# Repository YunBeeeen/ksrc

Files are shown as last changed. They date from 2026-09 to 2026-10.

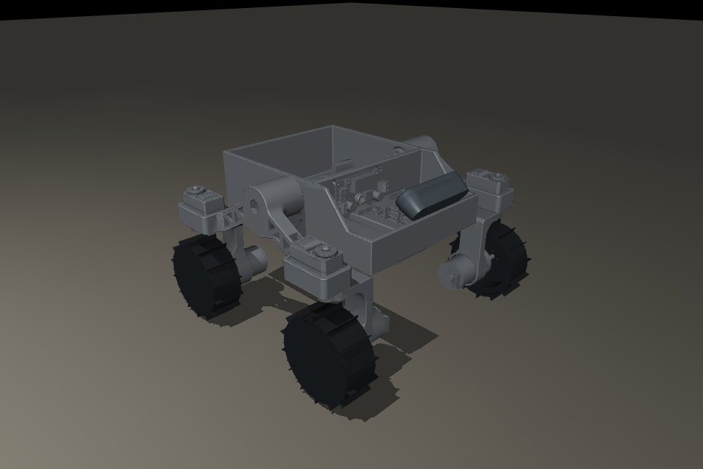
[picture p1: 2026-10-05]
ros/rover_description/docs/assembly_preview.png

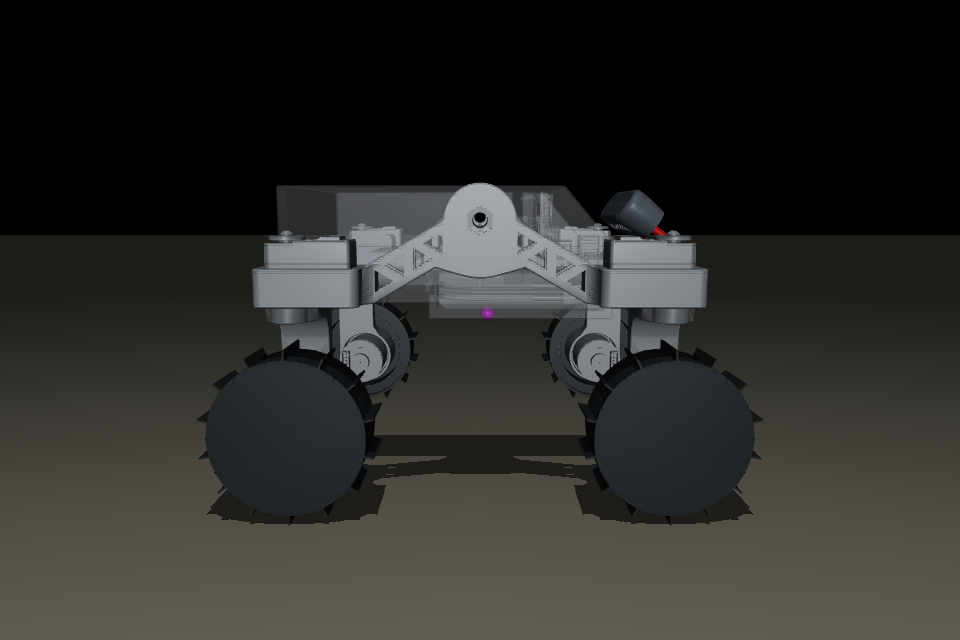
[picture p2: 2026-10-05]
ros/rover_description/docs/camera_35deg_com.png

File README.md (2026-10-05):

# KSRC 2026 — 4륜 독립조향 우주로버

2026 대한민국 우주로버 챌린지(우주항공청) 출전 로버의 **저수준 제어기 · 시뮬레이터 ·
강화학습** 코드베이스임.

바퀴 4개를 각각 독립 **조향** + **구동** 하는 스워브 방식임. 중앙 베벨 디퍼렌셜이
좌우 로커를 1:1 역방향으로 묶어 울퉁불퉁한 지형에서 네 바퀴 접지를 유지함.

| 항목 | 값 |
|---|---|
| 총질량 | 2.26 kg (규정 3 kg 이하) |
| 크기 | 284 × 263 × 173 mm (규정 300×300×200 이하) |
| 휠베이스 / 트랙 | 210 / 265 mm (조향축 = 바퀴 중심, 2026-10-03 실측. 이전 STL 183.6 / 236.7) |
| 바퀴 | 지름 79.9 mm, 폭 35 mm, 그라우저 약 28개 |
| 지상고 | 9.6 mm (다리 하우징 최저점 기준) |
| 구동 | SPG30E-GR131 ×4 (12V, 131:1, 76 rpm 무부하, 20 kg·cm 정지토크) |
| 조향 | FEETECH STS3215 ×4 (반이중 UART 버스, 1 Mbaud). 가동범위: 바퀴별 ±100° (펌웨어 `joint.c` = 시뮬 `config.steer_*_deg`, 조립 후 실측으로 확정) |
| 최고 속도 | 0.318 m/s |
| 배터리 | 3S 650mAh 120C 리포 |
| MCU / SBC | STM32 Nucleo-F446RE / Raspberry Pi 5 + AI HAT |

---

## 시스템 구조

```
        조작자 / 자율
             │
    ┌────────┴────────┐
    │  Raspberry Pi 5 │   pi/teleop        조이스틱 → cmd_vel
    │                 │   Nav2 (MPPI/Omni) 경로 → cmd_vel   ← 시뮬 검증 완료
    │                 │   (계획) D435 ICP  대회장 맵 정합 → 절대 위치
    │                 │   RL 정책          cmd_vel 위의 잔차 보정
    └────────┬────────┘
             │  아스키/바이너리 시리얼 (115200)
    ┌────────┴────────┐
    │ Nucleo-F446RE   │   swerve_kinematics.c   cmd_vel → 바퀴 4개 각·속도
    │                 │   swerve_fold_to_range  바퀴별 가동범위 안 등가해 선택
    │                 │   drive_align_gate.c    큰 조향 전환 중 구동 보류
    │                 │   spi_link.c            Pi SPI2 명령/텔레메트리 프레임
    │                 │   mdd3a_driver.c        PWM
    │                 │   encoder.c             엔코더 4채널
    └────────┬────────┘
             │
      구동모터 ×4      조향서보 ×4
```

명령 인터페이스는 `cmd_vel = (vx, vy, ω)` 한 지점으로 모임. 조이스틱 · Nav2 ·
RL 잔차가 모두 같은 지점에 붙으므로 서로 교체 가능함.

**시뮬레이터가 펌웨어 C 코드를 그대로 호출함.** `sim/build.sh` 가
`firmware/common/*.c` 를 `libksrc_common.so` 로 빌드하고 파이썬이 ctypes 로 부름.
기구학을 파이썬으로 재구현하면 언젠가 반드시 어긋나는데, 정책이 기구학 위의
**잔차**를 학습하는 구조라 어긋나는 순간 정책이 통째로 무의미해짐.

---

## 저장소 구조

```
firmware/
  common/                   MCU 비의존 순수 C + 호스트 유닛테스트
  src2026-rover-firmware/   보드에 올라가는 CubeIDE 프로젝트 (별도 git 저장소)
pi/teleop/                  조이스틱 텔레옵 (Python)
ros/                        ROS2 / Nav2 통합
  make_maps.py              주행가능 마스크 -> Nav2 정적 맵
  maps/                     arena_{sand,rock}.{pgm,yaml}
  mujoco_bridge.py          MuJoCo <-> ROS2 (/odom /tf 발행, /cmd_vel 구독)
  nav2_params.yaml          Nav2 파라미터 (MPPI motion_model=Omni)
  nav2_ksrc.launch.py       최소 구성 런치
  rviz/ksrc.rviz            RViz 설정
sim/
  ksrc_common.py            펌웨어 C 를 ctypes 로 호출
  rl/                       MuJoCo 물리 + 강화학습
CLI.md                      전체 실행 명령 모음
```

### 폴더별 문서

| 폴더 | 문서 | 내용 |
|---|---|---|
| `firmware/` | [README](firmware/README.md) · [CLI](firmware/CLI.md) | STM32 저수준 제어기: 핀, 50Hz 제어주기, 설정값, 조향 영점·구동 세팅, 터미널 명령 |
| `sim/` | [README](sim/README.md) · [CLI](sim/CLI.md) | MuJoCo 물리, 강화학습 환경·보상, 학습·평가·재생, 설계상 선택, 학습 결과 |
| `ros/` | 이 문서 아래 "ROS2 / Nav2" | Nav2·RViz 클릭 주행, 대회맵 텔레옵 |
| `pi/` | [firmware/CLI.md §5·6](firmware/CLI.md) | 조이스틱 텔레옵, Pi ↔ Nucleo SPI 링크 |

---

## ROS2 / Nav2 실행

전체 인자는 **[CLI.md](CLI.md)** 에 있다. 학습·평가 명령은 [sim/CLI.md](sim/CLI.md).

### Nav2 + RViz 로 클릭 주행

```bash
# 브리지 + Nav2 + RViz 를 한 번에 실행한다 (기존 별도 브리지는 먼저 종료).
cd /home/eomyunbeen/ksrc/ros && source /opt/ros/humble/setup.bash
python3 make_maps.py                      # 맵이 없으면 한 번
# 아래 둘 중 하나만 실행
ros2 launch nav2_ksrc.launch.py terrain:=sand           # 순수 IK
ros2 launch nav2_ksrc.launch.py terrain:=sand rl:=true  # 구형 s2 정책 적용 확인용
```

브리지는 `/cmd_vel`을 0.10초 시정수로 필터링해 `/cmd_vel_filtered`로 내고,
`/rl_action`(정규화 행동), `/rl_delta`(요청 보정), `/cmd_vel_applied`(포화 후 IK 입력)를
발행한다. 보정 적용은 `/cmd_vel_filtered`와 `/cmd_vel_applied`를 비교하면 된다.
`ros2 service call /set_rl std_srvs/srv/SetBool '{data: false}'`로 주행 중 끄고
`'{data: true}'`로 다시 켤 수 있다. 정책 모델은 `rl_model`, `rl_vecnorm` 런치
인자로 바꿀 수 있다. `cmd_filter_tau:=0`은 명령 필터 비교용이다.
기본 `rl:=true`가 불러오는 `runs/s2`는 이번 경로·관측 수정 이전 모델이므로
성능 개선 판정에는 쓰지 않는다. 새 모델은 재학습 후 `rl_model`과 `rl_vecnorm`을
명시한다.

RViz 상단 **"2D Goal Pose"** 로 지도를 클릭하면 로버가 그쪽으로 감.
회색이 주행가능, 검정이 통과 불가(경사 21° 초과)임.
목표 허용오차가 0.15m 이므로 로버 바로 옆을 찍으면 이미 도착한 것으로 판정될 수 있다.
이 런치는 시뮬 전용 ROS 도메인 77과 localhost 통신을 사용해 다른 ROS 노드의
`/odom`·`/map_server`와 섞이지 않게 한다. 진단 명령도 같은 도메인에서 실행한다:

```bash
source /opt/ros/humble/setup.bash
export ROS_DOMAIN_ID=77 ROS_LOCALHOST_ONLY=1
ros2 lifecycle get /bt_navigator         # active 여야 목표를 받는다
ros2 topic hz /odom                       # 브리지 위치가 계속 발행되는지 확인
```

전복 시 브리지는 구동을 멈추되 물리는 계속 진행하며, 자동으로 스폰으로 순간이동하지 않는다. 다시 시작하려면 별도 터미널에서
위 두 환경변수를 설정하고 `ros2 service call /reset_sim std_srvs/srv/Trigger '{}'` 를 실행한다. 같은 초기 스폰으로 돌아간다.
RViz 의 "2D Pose Estimate" 는 시뮬 스폰을 바꾸지 않는다. RViz 주행에서 RL 잔차는
런치 인자 `rl:=true`를 준 경우에만 적용된다.

컨트롤러는 **MPPI (`motion_model: Omni`)** 를 씀. `nav2_regulated_pure_pursuit_controller`
는 differential/ackermann 용이라 `(v, ω)` 만 내고 스워브의 게걸음(`vy`)을 버림.
실측으로 MPPI 가 `vy = 0.057` 을 명령하는 것을 확인함.

측위는 브리지가 `map→odom` 을 **항등으로** 발행함 (참값). 그래서 "Nav2 가 우리 로버에
맞게 도는가" 만 남고 측위 문제가 섞이지 않음. 실제 측위(D435 지형 ICP)가 되면 그
항등 변환만 갈아끼우면 됨.

Nav2 정적 맵은 경사·단차의 통행 가능성만 표시한다. `drivable_mask`의 0.16m 창은
지형 기울기를 측정하는 규모이며 차체 충돌 반경이 아니다. Nav2에는 바퀴 위치와
반경에서 계산한 약 0.21m 풋프린트와 0.24m inflation을 적용한다 (2026-10-03 실측 치수, 이전 0.19/0.22). 목표점이
턱에 너무 가까우면 반경 밖의 도달 가능한 지점으로 경로가 끝날 수 있다
(플래너 허용오차 0.15m). 순수 IK 경로도 같은 중심 이격 기준으로 만든다.

격리된 Nav2 검증에서 턱을 사이에 둔 `(-1.1, 0.2) → (0.4, 0.2)` 경로의
통행 불가 영역 최소 이격은 기존 약 3cm에서 수정 후 22.1cm로 늘었다 (이전 치수 기준 기록).
기본 스폰 `(0.121, 0.661)`에서 `(-1.1, 0.2)`로 실제 MuJoCo 주행도 성공했고,
로버 중심 최소 이격은 23.5cm였다. 이 검증은 순수 IK, 참값 측위 조건이다.

### 대회맵 + 기존 조이스틱 텔레옵

첫 터미널에서 대회맵, MuJoCo 로버, RViz를 띄운다. 텔레옵 모드에는 Nav2
컨트롤러를 띄우지 않아 `/cmd_vel` 명령이 충돌하지 않는다.

```bash
cd ~/ksrc/ros
source /opt/ros/humble/setup.bash
ros2 launch nav2_ksrc.launch.py terrain:=sand mode:=teleop
```

두 번째 터미널에서 **기존** 마우스 조이스틱을 ROS 모드로 실행한다. 왼쪽 패드로
전후·게걸음, 오른쪽 패드 또는 Q/E로 회전하고 스페이스바로 멈춘다.
급격히 주행 방향을 바꾸면 텔레옵 브리지가 먼저 감속한다. 네 바퀴가 새 방향으로
조향된 뒤 구동하는 규칙은 학습·평가·RViz 주행에도 공통 적용된다.
`teleop_guard:=false`는 사전 감속만 끄고,
`drive_align_gate_deg:=0`은 공통 조향각 구동 게이트를 끈다.

```bash
cd ~/ksrc
source /opt/ros/humble/setup.bash
export ROS_DOMAIN_ID=77 ROS_LOCALHOST_ONLY=1
python3 pi/teleop/teleop_joystick.py --ros --max-lin 0.25 --max-ang 0.8
```

`terrain:=rock`은 암석 대회맵으로 바꾼다. 이 모드의 RViz는 맵과 위치를 보여주는
화면이고 목표 주행 명령은 받지 않는다. 기존 `--port /dev/ttyACM0` 방식은 실기
Nucleo용 직렬 경로로 그대로 유지된다. 규사맵에서는 최초 스폰과 `/reset_sim`
위치를 3° 이하 평탄 구역으로 제한한다. [세 모드의 전체 CLI](CLI.md#6-대회맵-주행-rviz-목표-또는-텔레옵).

### 펌웨어 · 실기 텔레옵

빌드·플래시·터미널 명령·조향 영점·구동모터 확인·조이스틱 주행은
**[firmware/CLI.md](firmware/CLI.md)**, 설정값은 [firmware/README.md](firmware/README.md).

```bash
cd firmware/src2026-rover-firmware && ./build.sh --flash
python3 pi/teleop/teleop_joystick.py --port /dev/ttyACM0 --max-lin 0.15 --max-ang 0.8   # 저장소 루트에서
```

---

## 설계상 중요한 선택

시뮬·학습 쪽 설계 결정(잔차 정책 구조, 흙 모델, 보상, 랜덤화 등)은
[sim/README.md](sim/README.md#설계상-중요한-선택)로 옮겼다.

---

## 현재 상태

| 항목 | 상태 |
|---|---|
| 펌웨어 | 플래시·터미널·기구학 주행·워치독은 **이전 구조**에서 실기 검증. 2026-09-29 이후 50Hz 제어주기·정렬 게이트·SPI2 링크·IMU·서보 피드백으로 재구성 — **미플래시, 실기 미검증**. 조향 영점·바퀴별 범위·구동모터 부호는 조립 후 확인 |
| 시뮬 물리 | 검증 13종 통과. 슬립모델이 고착 재현 확인 |
| 지형 | 실측 규사 경사지형(기복 450 mm, 최대 30°) 통계에 맞춘 절차 생성 확인 |
| 경로추종 | `s4_route_fix` 400만 스텝 모델은 미학습 규사 경로에서 순수 IK보다 횡오차·슬립·잔차 포화가 커졌다. 현재 보상 `balanced`는 수정 후 **아직 재학습·성능 검증 전** |
| 측위 | **미해결.** 엔코더+IMU 데드레커닝은 1.7 m 주행에 845 mm 오차(슬립 때문). D435 + 대회장 맵 ICP 가 기하적으로 가능함을 확인, 미구현 |
| Nav2 | **시뮬에서 동작 확인.** MPPI(Omni) 주행과 선택적 `rl:=true` 잔차 적용을 `/goal_pose` 종단 시험으로 확인. 정책 적용은 성능 개선 검증과 별개이며 실기는 측위 선행 |
| 텔레옵 + 대회맵 | 기존 pygame 조이스틱의 ROS 모드에서 `/cmd_vel`→MuJoCo 이동·패드 해제 후 정지, `/map` 발행 종단 시험 통과 |
| teacher-student | teacher 가 특권 잠재변수를 거의 안 씀(ablation 노이즈 수준) → 증류 보류 |

학습 결과 상세(`s3_path_reward` 검증 등)와 알려진 제약은 [sim/README.md](sim/README.md#학습-현황).

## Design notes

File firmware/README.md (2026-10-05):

# KSRC 로버 펌웨어 (STM32 Nucleo-F446RE)

4륜 독립조향 스워브 로버의 저수준 제어기. 차체 속도 명령 `(vx, vy, ω)` 를 받아
바퀴 4개의 조향각(STS3215 서보)과 구동(MDD3A + 기어드 DC 모터)으로 바꾸고,
엔코더·서보·IMU 값을 Raspberry Pi 로 올려 보낸다.

> 실행 명령만 필요하면 **[CLI.md](CLI.md)**. 이 문서는 설정값과 구조의 정본이다.
> 상태 기준일: 2026-10-03. 2026-09-29 이후 변경(50Hz 제어주기, 정렬 게이트, SPI2 링크,
> IMU, 서보 피드백)은 **빌드는 되지만 실기 검증 전**이다.

---

## 1. 폴더 구조

```
firmware/
├─ README.md                  이 문서 (설정값 정본)
├─ CLI.md                     실행 명령 모음
├─ common/                    MCU 비의존 순수 C. 호스트 gcc 테스트 + 시뮬이 ctypes 로 같은 코드 호출
│   swerve_kinematics.c         역기구학 + 가동범위 안 등가해 선택 (swerve_fold_to_range)
│   drive_align_gate.c          큰 조향 전환 중 구동 보류
│   spi_link.c                  Pi <-> Nucleo SPI 144바이트 프레임 (CRC16)
│   mdd3a_driver.c              m/s -> 정규화 duty
│   sts3215_protocol.c          (시뮬 전용) 서보 패킷
│   teleop_protocol.c           (시뮬 전용) UART 바이너리 프레임
│   tests/                      호스트 유닛테스트
└─ src2026-rover-firmware/    보드에 올라가는 프로젝트 (Makefile + build.sh)
    Core/Src/main.c             50Hz 제어주기, 터미널 명령, 텔레메트리 조립
    Core/Src/joint.c            서보 각도 <-> 위치값, 바퀴별 가동범위, 피드백 읽기
    Core/Src/sts3215.c          STS3215 버스 (USART3 반이중)
    Core/Src/motor.c/encoder.c  MDD3A PWM 8채널, 엔코더 타이머 4개
    Core/Src/pi_spi.c           SPI2 슬레이브 (Pi 링크, DMA)
    Core/Src/imu_ism330.c       ISM330DHCX (SPI3 마스터)
    Core/Src/{swerve_kinematics,drive_align_gate,spi_link,mdd3a_driver}.c
                                -> ../../../common/ 심볼릭 링크
```

`common/` 의 C 를 고치면 시뮬도 같이 바뀐다 (`sim/build.sh` 로 `.so` 재빌드).

---

## 2. 하드웨어와 핀

MCU 클럭: **HSI 16 MHz, PLL 없음** (APB1 = APB2 = 16 MHz).
USART2/USART3/SPI2/SPI3 는 CubeMX 가 아니라 **레지스터로 직접** 설정한다.
`.ioc` 로 Generate Code 를 하면 `MX_SPI2_Init()`/`MX_SPI3_Init()` 이 생기는데 호출하지
않는다 (HAL SPI 가 Makefile 에 없어 링크도 깨진다).

| 기능 | 주변장치 | 핀 | 설정 |
|---|---|---|---|
| 터미널 / 조이스틱 | USART2 (ST-Link VCP) | PA2 TX, PA3 RX | 115200 8N1, RX 인터럽트 |
| 조향 서보 버스 | USART3 반이중 | PB10 (오픈드레인+풀업) | 1 Mbps |
| Pi 링크 | SPI2 슬레이브 + DMA1 S3/S4 | PB12 CS (GPIO+EXTI, 소프트웨어 NSS), PB13 SCK, PC2 MISO, PC3 MOSI | 모드 0, 8비트, Pi 쪽 1 MHz 권장 (상한 8 MHz) |
| IMU | SPI3 마스터 | PC10 SCK, PC11 MISO, PC12 MOSI, PC9 CS | 모드 0, 1 MHz |
| 구동 MOTOR1 (LF) | TIM2 CH1/CH2 | PA5 / PB3 | MDD3A #1 M1 (A/B) |
| 구동 MOTOR2 (LB) | TIM12 CH1/CH2 | PB14 / PB15 | MDD3A #1 M2 |
| 구동 MOTOR3 (RF) | TIM3 CH1/CH2 | PA6 / PA7 | MDD3A #2 M1 |
| 구동 MOTOR4 (RB) | TIM3 CH3/CH4 | PB0 / PB1 | MDD3A #2 M2 |
| 엔코더 1~4 (LF, LB, RF, RB) | TIM1 / TIM4 / TIM5 / TIM8 | PA8·PA9 / PB6·PB7 / PA0·PA1 / PC6·PC7 | x4 쿼드러처 (TIM5 만 32비트) |

PWM: ARR 799 → 약 20 kHz, duty -799 ~ +799. MDD3A 는 PWM+PWM 방식 (정방향 A, 역방향 B).
서보 VCC 는 STM32 에 연결하지 않는다 (12V 외부 전원, GND 만 공통).

---

## 3. 제어 흐름 (50 Hz)

```
UART "V vx vy ω"  ─┐
SPI2 명령 프레임   ─┴─> 목표 (vx, vy, ω) 만 갱신
                          │
20 ms 마다 (main.c while 루프)
  1. 엔코더 속도 추정 (dt 는 DWT 사이클 카운터)
  2. 센서: 서보 4개 피드백 (위치·속도·부하·전압·온도·상태), IMU 1샘플
  3. 워치독: 500 ms 무명령 -> 목표 0 (조향각은 유지)
  4. swerve_ik_compute         -> 모듈별 (각, 속도), 바퀴 속도 상한 초과 시 전체 비율 축소
  5. swerve_fold_to_range      -> 바퀴별 가동범위 안의 등가각 (θ 또는 θ±180° + 역회전)
  6. 조향 SYNC_WRITE           -> 모듈 순서를 서보 순서로 재배열
  7. drive_align_gate          -> 큰 조향 전환 중이면 구동 0
  8. 구동 PWM                  -> MOTOR_DRIVE_SIGN 적용
  9. 텔레메트리 프레임          -> 다음 SPI 전송에 실림
```

3~9 는 텔레옵(첫 구동 명령)이 시작된 뒤에만 돈다. 그 전에는 `T`, `MOT`, `MTEST` 같은
수동 명령이 액추에이터를 쓴다.

---

## 4. 설정값

**확정** = 실측·결정됨, **임시** = 조립 후 확인 필요, **가정** = 데이터시트/추정.

### 4.1 서보 배치와 조향

| 설정 | 위치 | 현재 값 | 상태 |
|---|---|---|---|
| 서보 ID ↔ 바퀴 | `joint.c` `joint_config[]` | 서보1 LF, 서보2 LB, 서보3 RF, 서보4 RB | 확정 |
| 모듈 → 서보 | `main.c` `SWERVE_MODULE_SERVO` | `{0, 2, 1, 3}` (FL→서보1, FR→서보3, RL→서보2, RR→서보4) | 확정 |
| 조향 영점 | 서보 EEPROM (`ZERO`) | 미기록 | **임시** — 조립 후 |
| 영점 위치값 | `joint.c` `.offset` | 2048 (`ZERO` 가 현재 자세를 2048 로 기록) | 확정 |
| 조향 방향 | `joint.c` `.dir` | 전부 +1 | **임시** — `T 30` 이 위에서 반시계면 +1. 뒤쪽 서보(LB, RB)는 앞쪽과 **월드 z축 기준 180°** 돌려 장착(둘 다 아래를 봄) → 회전 방향은 같으므로 네 서보 `dir` 부호는 같아야 함. 영점 차이는 `ZERO ALL` 이 흡수 |
| 가동범위 | `joint.c` `.min_deg/.max_deg` | 전부 -100° ~ +100° | **임시** — 조립 후 실측. 폭 ≥ 180° 유지 |
| 시뮬 가동범위 | `sim/rl/config.py` `steer_lo_deg/steer_hi_deg` | 전부 ±100° (순서 FL, FR, RL, RR) | 펌웨어와 **같이** 고칠 것 |
| 조향 0° 의 뜻 | — | 바퀴 정면, 구동모터 몸체 안쪽, + 는 위에서 반시계 | 확정 (시뮬과 동일) |
| 서보 최고속 | `joint.c` `joint_goal_speed` | 0 = 서보 최대 (제한 없음). 터미널 `S` 로 변경 | 단위 step/s, 4096 step = 360° |
| 서보 가속도 | `joint.c` `joint_init()` | 50 | 가정 (단위 미실측) |
| 서보 수신 타임아웃 | `sts3215.c` `STS_RX_TIMEOUT_MS` | 3 ms | 확정 |
| 서보 읽기 실패 재시도 | `main.c` `SERVO_RETRY_TICKS` | 25 주기 (0.5 s), 한 주기에 1개만 재시도 | 확정 |

±100° 에서 모든 방향이 나온다: 한 방향의 해는 θ(정회전)와 θ±180°(역회전) 두 개이고
가동 폭이 200° 라 항상 하나는 범위 안이다. ±80°~±100° 는 두 해가 겹쳐 경계 근처
흔들림에 반전이 생기지 않는다. 경계를 넘으면 180° 반전이 일어나고 그동안 구동은
정렬 게이트가 멈춘다.

### 4.2 구동과 엔코더

| 설정 | 위치 | 현재 값 | 상태 |
|---|---|---|---|
| 모터 번호 ↔ 바퀴 | — | MOTOR1 LF, MOTOR2 LB, MOTOR3 RF, MOTOR4 RB (조향 서보와 같은 배치) | **확정 2026-10-03** |
| 모듈 → 구동모터 | `main.c` `SWERVE_MODULE_MOTOR` | `{MOTOR1, MOTOR3, MOTOR2, MOTOR4}` (FL, FR, RL, RR) | 확정 |
| 구동 부호 | `main.c` `MOTOR_DRIVE_SIGN[MOTOR1..4]` | −1, −1, +1, +1 (LF, LB, RF, RB) | 2026-10-03. 모터를 넷 다 같은 방식으로 달아 **좌우 대칭** (L −1, R +1). RF 는 −1 로 관찰돼 확인 필요 |
| 엔코더 부호 | `main.c` `ENCODER_SIGN[MOTOR1..4]` | −1, −1, +1, +1 | MOTOR1 이 duty + 에서 tick + (실측) → 구동 부호와 같음. `V 0.05 0 0` 에서 m/s 가 넷 다 + 인지 확인 |
| 기어비 | `main.c` `GEAR_RATIO` | 131 (SPG30E-GR131) | 확정 |
| 엔코더 PPR | `main.c` `ENCODER_PPR` | 16 (x4 → 64, 바퀴 1회전 8384 틱) | **확정 2026-10-03** (무부하 77.8 rpm) |
| 바퀴 반경 | `main.c` `WHEEL_RADIUS_M` | 0.03995 m (지름 79.9 mm, STL) | 가정 (캘리퍼 미실측) |
| 바퀴 최고속 | `main.c` `SWERVE_MAX_WHEEL_MPS` | 0.318 m/s (= duty 100%) | 가정. 실측 무부하 0.325 m/s (+2%) |
| 모듈 위치 | `main.c` `SWERVE_MODULES` | (±0.105, ±0.1325) m (조향축 = 바퀴 중심) | **실측 2026-10-03**. 시뮬 `axle_x=0.105`, `track=0.265` 와 동일 |

조립 전 날것 방향 기록 (`MOT`, 부호 보정 없음, 샤프트 끝에서 볼 때):

| 모터 | duty + | 엔코더 | 날짜 |
|---|---|---|---|
| MOTOR1 | 반시계 | + | 2026-10-03 |
| MOTOR2~4 | | | |

### 4.3 제어주기와 안전

| 설정 | 위치 | 현재 값 |
|---|---|---|
| 제어주기 | `main.c` `CTRL_PERIOD_MS` | 20 ms (50 Hz, 시뮬 `CTRL_HZ` 와 동일) |
| 명령 워치독 | `main.c` `TELEOP_TIMEOUT_MS` | 500 ms → 목표 0 |
| 정렬 게이트 트리거 | `main.c` `DRIVE_GATE_TRIGGER_DEG` | 60° (목표 급변, 또는 목표-실측 차이) |
| 정렬 게이트 해제 | `main.c` `DRIVE_GATE_RELEASE_DEG` | 10° (네 바퀴 실측각 기준) |
| 정렬 게이트 타임아웃 | `main.c` `DRIVE_GATE_MAX_HOLD_MS` | 1500 ms → 강제 해제 + `GATE_TIMEOUT` 플래그 |
| 모터 자가시험 | `main.c` `s_mtest_enabled` | 기본 OFF (`MTEST` 로만) |
| 로그 | `main.c` `s_log_enabled` | 부팅 시 ON, 텔레옵 시작 시 자동 OFF |

안전장치 요약:
- 손 떼면(속도 0) 조향각을 유지한다. 0° 로 튀지 않는다.
- 조향 해는 항상 가동범위 안. `joint.c` 가 한 번 더 클램프한다 (`T` 포함).
- 서보는 위치값 사이를 직선으로 움직여, 범위 안 두 각 사이의 이동 경로도 범위 안이다.
- 큰 조향 전환 중에는 구동 0 (정렬 게이트). 최대 1.5 초.
- 명령이 끊기면 500 ms 뒤 정지. 조이스틱 프로그램은 창 포커스 잃음·스페이스·종료 시 0 전송,
  패드 중심 10% 데드존.

### 4.4 IMU (ISM330DHCX)

| 설정 | 값 |
|---|---|
| 가속도 | 208 Hz, ±4 g (0.122 mg/LSB) |
| 자이로 | 208 Hz, ±500 dps (17.5 mdps/LSB) |
| 기타 | BDU=1, 주소 자동증가. 부팅 시·1초마다 WHO_AM_I(0x6B) 확인, 끊기면 재초기화 |
| 좌표계 | **센서 좌표계 원시값**. 차체 좌표계 회전은 Pi 에서 (장착 방향 확인 필요) |

---

## 5. 통신

### 5.1 USART2 아스키 (터미널 · 조이스틱)
한 줄 명령. 구동은 `V vx vy ω` (m/s, m/s, rad/s, x=전진 y=좌측 ω=반시계 +).
전체 명령은 [CLI.md](CLI.md#3-터미널-명령).

### 5.2 SPI2 프레임 (Pi)
정본: `common/spi_link.h`. Pi 쪽: `pi/common/nucleo_link.py` (`SpiLink`).

- 양방향 **144 바이트 고정**, 동기 `A5 5A`, 버전 2, CRC-16/CCITT-FALSE.
- Pi → Nucleo: 속도 명령 (`0x01`) 또는 폴링 (`0x00`, 워치독 갱신 안 함).
- Nucleo → Pi: 한 제어주기의 값 전부 + Nucleo 시각 `t_ms`.
  구동(적용 명령, 엔코더 틱, 바퀴 속도, duty), 조향(목표각, 실측 각·속도·부하·전압·온도·상태,
  유효 비트), IMU(원시 6축), 상태 플래그(워치독, 게이트 대기, 게이트 타임아웃, 서보 읽기 실패,
  조향 클램프, IMU 유효, 명령 출처). 배열은 모듈 순서 FL, FR, RL, RR.
- 받는 텔레메트리는 **직전 CS 해제까지 만든 것** (0~40 ms 묵음). 같은 `tick` 을 두 번
  받을 수 있다. Nucleo 가 없으면 CRC 실패로 `None`.

---

## 6. 세팅 CLI 요약

자세한 순서와 설명은 [CLI.md](CLI.md).

```bash
# 빌드 + 플래시 (보드 USB 연결)
cd ~/ksrc/firmware/src2026-rover-firmware
./build.sh --flash

# 터미널
python3 -m serial.tools.miniterm /dev/ttyACM0 115200
```

```
LOG                       로그 끄기
SCAN                      서보 ID 1~4 확인
OFF                       토크 해제 -> 네 바퀴 정면 정렬 (모터 안쪽)
ZERO ALL                  영점 기록 (EEPROM)
ON
T 0 0 0 0                 네 바퀴 정면 확인
T 30 / T 0 30 / T 0 0 30 / T 0 0 0 30
                          서보별 방향 확인 (위에서 반시계가 정상, 아니면 joint.c .dir = -1)
S 1500                    (선택) 조향 최고속 제한 ~132°/s
MOT 1 300 1000            구동모터 1 을 duty +300 으로 1초 (바퀴 띄우고)
MOT 1 799 2000            무부하 rpm 확인 (2초 이하로, 16비트 엔코더 한계)
```

```bash
# 조이스틱 (miniterm 닫고, 처음엔 바퀴 띄우고 저속)
cd ~/ksrc
python3 pi/teleop/teleop_joystick.py --port /dev/ttyACM0 --max-lin 0.15 --max-ang 0.8
```

```bash
# 라파에서 (ssh pi@raspberrypi.local, SPI 로 Nucleo 와 통신)
cd ~/ksrc
python3 pi/common/spi_monitor.py         # 텔레메트리 확인 (명령 안 보냄)
python3 pi/common/imu_check.py           # IMU 축·부호 확인 (로버 좌표)
python3 pi/common/udp_spi_bridge.py      # PC 조이스틱 -> SPI 중계 (켜 둔다)
```

```bash
# PC 에서 (조이스틱 창은 PC, 라파가 받아 SPI 로 전달)
python3 pi/teleop/teleop_joystick.py --udp raspberrypi.local --rate 50 --max-lin 0.15 --max-ang 0.8 --monitor
```

---

## 7. 조립 후 반드시 할 것 (주행 전)

| # | 항목 | 고칠 곳 | 방법 |
|---|---|---|---|
| Z1 | 조향 영점 | 서보 EEPROM | `OFF` → 정면 정렬 → `ZERO ALL` → `ON` → `T 0 0 0 0` |
| Z2 | 조향 방향 | `joint.c` `.dir` | `T 30` 을 서보별로, 위에서 반시계면 +1 |
| Z3 | 가동범위 | `joint.c` `.min/.max_deg` **+** `sim/rl/config.py` | `T` 로 천천히 늘려 간섭각 확인 |
| Z4 | 구동모터 ↔ 바퀴 | `main.c` `SWERVE_MODULE_MOTOR` | 바퀴 띄우고 `MOT n 300 1000` |
| Z5 | 구동 방향 | `main.c` `MOTOR_DRIVE_SIGN` | `V 0.05 0 0` 에서 뒤로 도는 바퀴의 모터 → -1 |
| Z6 | 엔코더 방향 | `main.c` `ENCODER_SIGN` | Z5 후 `LOG` m/s 가 음수인 모터 → -1 |

Z1 → Z2 → Z3 순서대로. 같은 목록이 옵시디언 `실기 확인 목록` 0절에 있다.

---

## 8. 테스트

```bash
# 공용 C (호스트)
cd ~/ksrc/firmware/common/tests
for t in swerve_kinematics drive_align_gate spi_link mdd3a_driver; do
  gcc -std=c99 -Wall -Wextra -I.. -o /tmp/t_$t test_$t.c ../$t.c -lm && /tmp/t_$t | tail -1
done

# Python <-> C 프레임 교차검증
cd ~/ksrc && bash sim/build.sh && python3 pi/common/test_spi_link.py
```

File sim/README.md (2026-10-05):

# KSRC 시뮬레이터 · 강화학습 (`sim/`)

MuJoCo 물리 + 슬립-침하 흙 모델 위에서, 펌웨어와 **같은 C 기구학**(`firmware/common/`)을
ctypes 로 호출해 경로추종 잔차 정책을 학습·평가한다. 로버 전체 개요는 [루트 README](../README.md),
펌웨어 설정은 [firmware/README.md](../firmware/README.md), 전체 학습 명령은 **[CLI.md](CLI.md)**.

> 명령은 특별한 말이 없으면 **저장소 루트(`~/ksrc`) 기준**이다.

---

## 구성

### `sim/rl/` — MuJoCo 물리 + 강화학습

| 파일 | 역할 |
|---|---|
| `config.py` | 로버 물리 파라미터 + 센서/구동 노이즈. 출처를 [확정]/[추정]/[미정] 3등급 표기 |
| `mjcf.py` | config → MuJoCo MJCF 모델 생성 |
| `terramech.py` | 슬립-침하 모델. 고착 재현의 핵심 |
| `terrain.py` | 절차 지형 생성 · 대회장 맵 로드 · 주행가능 마스크 · 미세요철 교란 |
| `path.py` | 기준경로 생성 + 홀로노믹 pure pursuit (Nav2 컨트롤러 미러링) |
| `reward.py` | 단일 보상 함수와 가중치 (`RewardCfg`) |
| `env.py` | Gymnasium 환경 |
| `train.py` | PPO 학습 (stable-baselines3) |
| `eval.py` | 대회장 지형 평가. 고전 제어 기준선 4종과 비교 |
| `traction.py` | 고전 제어 기준선 (경사스케줄 듀티 제한 / 엔코더 TCS) |
| `nets.py` | teacher-student 신경망 (특권 인코더 / 적응 모듈) |
| `distill.py` | teacher → student 증류 (DAgger + 잠재변수 회귀) |
| `probe_teacher.py` | teacher 가 특권정보를 실제로 쓰는지 진단 |
| `view.py` | MuJoCo 뷰어 (정책 재생). `--path` 로 지정 경로, `--stage1` 로 학습 조건 재현 |
| `draw_path.py` | 지형 지도에서 마우스로 경로 찍기 |
| `check_model.py` | 모델 물리 검증 13종 |
| `test_terramech.py` | 견인력 곡선·고착 재현 검증 |
| `plotlog.py` | 학습 로그 → 그림 |
| `draw.py` | 모델 2D 단면 렌더 |

---
---

## 실행 명령

전체 인자는 **[CLI.md](CLI.md)** 에 있음. 아래는 자주 쓰는 것만임.

### 빌드 · 검증

```bash
cd sim && bash build.sh          # 기구학 C → libksrc_common.so
cd rl  && python3 check_model.py # 물리 검증 13종
python3 test_terramech.py        # 견인력 곡선 검증
```

### 학습

```bash
cd sim/rl

# Stage 1 — 경로추종 sanity check (경로 세트 고정, 랜덤화·교란·커리큘럼 OFF)
python3 train.py --steps 1000000 --envs 16 --terrain sand --stage1 --out runs/s5_reward

# Stage 2 — 랜덤화·커리큘럼 켜고 특권 관측(teacher) 붙임
python3 train.py --steps 4000000 --envs 16 --teacher --terrain sand --out runs/foo
```

| 옵션 | 뜻 |
|---|---|
| `--stage1` | 경로 세트 고정(10개) + 랜덤화·노이즈·교란·커리큘럼 전부 OFF. **3D 잔차가 경로추종을 배우는지만** 본다 |
| `--terrain sand\|rock\|proc` | `sand`/`rock` 은 대회장 맵 고정, `proc` 은 절차 생성 |
| `--teacher` | 특권 관측을 붙임 (Stage 2) |
| `--path-seed` / `--n-paths` | Stage 1 경로 세트. **학습과 평가는 다른 seed** 를 써야 함 |
| `--gamma` | 기본 0.998 (시상수 10초). 0.99 는 50Hz 에서 2초라 완주 보너스가 안 보임 |
| `--drive-align-gate-deg` | 기본 10°. 60° 초과 큰 방향 전환 후 구동 재개 오차, 0이면 이전 동작과 비교 |
| `--w-energy` | 현재 미지원: 차축 부하 모델 검증 전에는 오류를 내고 학습을 시작하지 않음 |

### 현재 학습 환경 (`sim/rl/env.py`, `train.py`)

| 구성 | 현재 구현 |
|---|---|
| 물리·제어 주기 | MuJoCo 2 ms 물리 스텝 10회당 정책 1회(50 Hz). 에피소드 최대 20초/1000스텝 |
| 기준 제어 | 경로 위 pure pursuit가 `cmd_nom=(vx, vy, ω)` 생성 → 정책의 3차원 행동 `a∈[-1,1]^3`에 `(0.03 m/s, 0.03 m/s, 0.10 rad/s)`를 곱해 가산 → 공유 C 스워브 IK → 바퀴별 개루프 PWM 듀티·조향각 |
| 저수준 보호 | 바퀴 속도 한계를 넘으면 차체 명령을 공통 비율로 축소. 목표 조향각이 한 주기에 60° 넘게 바뀌면 네 바퀴가 목표의 10° 이내로 정렬될 때까지 구동 보류 |
| 경로·시작 | 경사 최대 21°·단차 최대 40 mm 마스크에서 바퀴 외접 반경 약 0.21 m와 여유 0.03 m를 더 확보한 경로를 생성 (2026-10-03 실측 치수, 이전 0.19 m). 고정 경로 세트에서는 경로 길이의 앞 0~60% 위치에서 시작하고 투영기 두 개도 그 위치에서 초기화. 초기 기수는 그 지점 접선의 ±30° |
| 관측 | 프레임당 36개(`cmd_nom`, 직전 바퀴 명령·엔코더 속도·조향각, 자세·IMU, 0.30/0.80 m 경로 샘플 2점, 횡오차, 기수오차의 cos/sin, 제어기 선행 목표점과 선행 거리 `L`, 직전 행동) × 50프레임 = 1800차원(1초 이력). `--teacher`는 흙·슬립·침하 등 특권값 43개를 추가해 1843차원 |
| 종료 | 목표까지 경로 잔여길이와 실제 거리 **모두** 0.25 m 미만이면 성공. 전복(roll/pitch 60° 초과), 최근 2초 이동 0.02 m 미만이면서 슬립 0.5 초과, 경계 이탈은 실패 종료. 20초 도달은 시간 만료 |

위 Stage 1 실행 예시(`--terrain sand --stage1`)는 고정 경로 10개(seed 1234), 원본 대회 높이맵,
고정 규사 파라미터를 쓴다. **센서·구동 노이즈, 물리 파라미터 랜덤화, 높이맵
교란, 커리큘럼은 꺼진다.** 경로 선택·시작 위치·기수·순항속도는 여전히 매
에피소드 달라진다. `train.py`의 `--terrain` 기본값은 `proc`이므로 Stage 1에서는
`--terrain sand`를 명시한다. `--terrain proc --stage1`은 **경로만 sand 맵에서
생성하고 지형은 proc으로 만드는 불일치**가 있어 현재 비교에 쓰지 않는다.
Stage 1 학습 경로 10개를 2 cm 간격으로 표본화하면 7개에 10° 이상 구간이
있고 6개는 시작점보다 끝점이 높다. 최고 경사는 약 15.3°다. 20° 이상과
30° 램프는 이 고정 경로에 포함되지 않으므로, 현재 Stage 1 결과로 급경사
등판 성능을 판단할 수 없다.
평가 경로는 별도 seed(기본 4321)로 생성해 같은 경로 암기를 구분한다.
암석맵(`rock`)은 이 이격(당시 0.22m, 지금 0.239m)을 적용하면 긴 2m 고정 경로가 나오지 않아
`--terrain rock --stage1`이 오류로 중단된다. 암석 구간은 별도의 짧은 임무
길이·목표 판정이 필요하며, 현재 Stage 1 성능 비교는 규사맵 기준이다.

Stage 2(`--stage1` 없음)는 `--terrain sand|rock`이면 해당 대회 높이맵을 쓰고
매 에피소드 미세요철을 교란한다(기본 표준편차 `0.020 m × 난이도`). `proc`이면
8×8 m 절차 지형을 새로 만든다. 흙 다짐·두께와 바퀴별 마찰 패치, 미측정
질량·로커 스토퍼, 배터리 전압, 엔코더·IMU 오차, 서보 응답, 0~2스텝 제어
지연, 저역통과된 측위 오차를 랜덤화한다. 최근 100개 에피소드 성공률이
60% 이상이면 난이도를 0.05씩 올린다. 학습기는 SB3 PPO, 관측·보상
`VecNormalize`, 기본 `γ=0.998`, 512스텝/환경 rollout, batch 4096,
6 epoch, 학습률 `3e-4`다. `--teacher`는 이 Stage 2의 선택 사항이다.

**현재 관측 제약:** 학습용 추종기는 `L=clip(pp_k_v × v_cruise, pp_l_min, pp_l_max)`만큼
경로를 따라 앞선 목표점 하나를 사용한다. 정책 관측에는 이 점의 차체좌표와
`L`을 별도로 넣고, 0.30/0.80 m 경로 샘플 두 점은 경로 모양을 전달한다.
Pure Pursuit의 목표점 하나와 경로 샘플 두 점은 서로 다른 역할이다.
ROS에서 현재 쓰는 Nav2 Omni MPPI에는 단일 Pure Pursuit 목표점이 없으므로
`/plan`에서 같은 선행 거리 규칙으로 정책용 참조점을 만든다. 나중에 제어기를
Pure Pursuit으로 교체하면 실제 선택한 목표점을 이 필드에 전달해야 한다.
관측이 1650→1800차원으로 바뀌어 기존 체크포인트는 새 환경에 로드되지 않으며
새 입력으로 다시 학습해야 한다. pure pursuit 명령·lookahead와 36차원 프레임의
`e_y`·`e_psi`는 같은 잡음 포함 추정 자세로 계산한다. 보상·종료 판정은 참값을
쓴다. 실기 투입에는 Nav2 측위·경로에서 같은 입력을 공급해야 하며,
ROS 브리지의 관측과 Stage 2 관측의 수치적 일치는 아직 별도 검증이 필요하다.

### 현재 보상 함수 (`sim/rl/reward.py`)

정책 행동을 적용해 **물리를 진행한 뒤** 참 위치로 보상을 계산한다. 경로 호길이
진행량을 `p=clip(Δs/(v_cruise·Δt), 0, 1)`, 실제 이동량을
`m=clip(‖Δxy‖/(v_cruise·Δt), 0, 1)`로 정규화한다. `Δs`는 한 주기의 실제
이동거리로 상한을 두어 코너를 잘라도 가짜 진행 보상을 받지 않는다.
`e_y`는 단조 진행 투영기의 경로 횡오차, `d_route`는 전체 경로 선분까지의
최근접 실거리, `e_psi`는 차체 기수와 경로 접선 사이의 각도다.
실제 이동 방향 `e_course`는 진단으로 기록하지만 현재 보상에는 쓰지 않는다.
경로 중앙으로 복귀하는 대각 이동에 방향 게이트를 걸면 교정 행동도 벌주기 때문이다.

```text
G = exp(-(e_y / 0.08 m)^2) · max(0, cos(e_psi))
Phi(s) = -0.25 d_route / (v_cruise·Δt)
F(s,s') = gamma·Phi(s') - Phi(s)       # 종료/시간만료 상태의 Phi = 0
r_step = 0.20 p + 0.80 p G
       - 0.04 m min((e_y / 0.08 m)^2, 4)
       + F(s,s')
       - 0.01 m min((e_psi / 0.35 rad)^2, 4)
       - 0.01 mean((a_t - 2a_(t-1) + a_(t-2))^2)
       - 0.06 mean(a_t^2)
```

완주 `+20`, 전복 `-10`, 고착 `-5`, 경계 이탈 `-10`은 해당 스텝에 한 번
더한다. 차체 헤딩 게이트는 논문과 같은 `max(0, cos(e_psi))`이다. 따라서
게걸음·후진에서는 **정렬 보상 80%가 0**이 되고 기본 진행 20%만 남는다.
이는 예전의 "차체 방향과 무관한 스워브" 목표에서 논문식 전방 선호로 바꾼 선택이다.
논문의 단위와 원계수는 제어주기·속도가 달라 복사하지 않았다.
옆방향 복귀가 당장 경로 진행을 줄여도 학습 신호를 얻도록 경로까지의
실거리 잠재함수를 추가했다. 이 항은 논문에는 없는 스워브용 확장이다.
단조 투영기의 국소 `e_y`는
코너에서 선분이 바뀌며 점프하므로 이 항에 쓰지 않는다. 전체 선분 최근접
실거리는 한 주기의 실제 위치 이동량보다 빠르게 변할 수 없다. 잠재함수는
할인율 `gamma`와 일치시키고 종료 시 값을 0으로 처리해 왕복 이동이
같은 시간 동안 정지해 있는 것보다 추가 할인 보상을 만들지 못하게 했다.
보상 설정은 `RewardCfg` 하나만 사용한다. 가중치를 수정할 때는
`reward.py`를 변경하고 새 `--out` 디렉터리에서 학습한다. 학습 시작 시
`reward.py`와 보상 조립·종료 판정이 있는 `env.py`의 사본을 실행 디렉터리의
`src/`에 저장하므로 실험별 공식을 확인할 수 있다.
전력·에너지·슬립·침하는 **현재 진단 지표이지 보상 항이 아니다.** 차축 부하
모델이 미검증이라 에너지 가중치 옵션 `--w-energy`는 오류를 내고 중단한다.

| TensorBoard 항목 | 보상에서 하는 일 | 해석 |
|---|---|---|
| `reward/prog` | 경로 호길이 진행 `+0.20p` | 큰 횡오차에서도 전진할 유인을 남김 |
| `reward/align` | 횡오차·차체 헤딩 정렬을 통과한 진행 `+0.80pG` | 헤딩 90° 이상이면 0 |
| `reward/lat` | 이동 중 횡오차 벌점 | 음수. 0에 가까울수록 좋음 |
| `reward/recover` | 전체 경로 실거리의 할인 일치 잠재함수 변화 | 같은 시간의 왕복/정지에 추가 이득 없음 |
| `reward/head` | 이동 중 차체 기수오차의 유계 이차 벌점 | 논문식 헤딩 항을 수치적으로 제한 |
| `reward/course` | 기본 보상에서는 0 | 실제 이동 방향오차는 진단 지표로 남김 |
| `reward/smooth` | 행동의 2차 차분 벌점 | 잔차 명령이 갑자기 바뀌는 것을 억제 |
| `reward/resid` | 행동 크기 벌점 | 지속적으로 큰 잔차를 쓰는 것을 억제 |
| `reward/goal` | 경로 완주 시 한 번 `+20` | 에피소드 평균은 대략 `20 × 완주율` |
| `reward/tip` | 전복 시 `-10` | 실패 종료 벌점 |
| `reward/stuck` | 고착 시 `-5` | 실패 종료 벌점 |
| `reward/oob` | 경계 이탈 시 `-10` | 실패 종료 벌점 |

`reward/*` 그래프는 스텝 보상이 아니라 **에피소드별 항목 합계**를 최근 종료된
200개 에피소드에서 평균한 값이다. 에피소드 길이가 바뀌면 `align` 합계도
달라지므로, 경로추종 개선 여부는 `rollout/e_y_m`, `rollout/e_y_p90`,
`rollout/course_m`, `rollout/success`, `rollout/a_use`를 함께 확인한다.
이전 가중치(`sigma_y=0.10`, `w_lat=0.03`, `w_head=0.02`)로 학습한
`s5_paper_heading` 100만 스텝 정책은 미학습 경로 30쌍에서 IK와 완주율은
같고, 기수오차는 3.93° 줄었지만 평균 횡오차는 5.00 mm, 슬립은 0.07 늘었다.
그래서 20~30 mm 횡오차 차이를 더 구별하고 중복된 헤딩 이차 벌점을 줄였다.
급경사 보정까지 막지 않도록 잔차 벌점 `0.06`은 유지했다. **새 가중치의 성능은
재학습 후 같은 미학습 경로에서 IK와 비교해야 한다.**

로그는 `runs/<이름>/tb` 로 감. 실행마다 따로 쌓이므로 **전부 비교하려면 `--logdir runs`** 를 줌.
현재 `RoverEnv`는 조향 목표가 한 주기에 60° 넘게 바뀌는 큰 방향 전환에서만
네 바퀴 구동을 함께 보류하고, 모두 목표각의 10° 이내에 들면 다시 구동한다.
학습·평가·ROS 주행에 공통 적용된다. 저장된 `runs/s2`는 이 조향 대기와
새 경로추종 보상을 넣기 전에 학습했으므로 새 보상의 성능을 나타내지 않는다.
STM32 펌웨어도 같은 규칙(`firmware/common/drive_align_gate.c`)을 50Hz 제어주기에 적용한다.
실기에서는 서보 현재각을 버스로 읽어 판정하며, 아직 실기 검증 전이다.

### 재생 (play)

```bash
cd sim/rl

# 순수 기구학 (잔차 0) — 기준선 확인
python3 view.py --terrain sand --d 1.0 --realtime      # --realtime 0.5 로 느리게

# 학습된 정책.  vecnorm 을 빼면 관측 스케일이 어긋나 결과가 무의미함
python3 view.py --terrain sand --stage1 --realtime \
        --model runs/s2/final --vecnorm runs/s2/vecnorm.pkl

# 학습 중 저장되는 최신 정책을 별도 MuJoCo 뷰어에서 자동 재생
python3 view.py --terrain sand --stage1 --watch-run runs/s9_watch

# 지형만 보기 (물리 정지)
python3 view.py --terrain rock --static
```

**`--stage1` 을 주면 학습과 같은 조건**(경로 세트 고정, 랜덤화 OFF)으로 재생함.
안 주면 경로가 매번 새로 생성되고 노이즈가 켜져서 학습 조건과 달라짐.

### 마우스로 경로 찍고 달려보기

MuJoCo 뷰어는 마우스 콜백이 없음(`launch_passive` 는 `key_callback` 만 받음).
그래서 위에서 본 2D 지도에서 찍고 그 경로를 재생함.

```bash
cd sim/rl
python3 draw_path.py --terrain sand --out mypath.npy
#   좌클릭 추가 · 우클릭/z 취소 · c 전체삭제 · Enter 저장 · q 취소
#   빨간 영역이 주행 불가 (경사 상한 21도).  구간별 통과 가능 여부를 표시해 줌

# 기준선 (잔차 0)
python3 view.py --terrain sand --path mypath.npy --realtime

# 정책
python3 view.py --terrain sand --path mypath.npy --realtime \
        --model runs/s2/final --vecnorm runs/s2/vecnorm.pkl
```

특정 경로에서 실패가 재현되므로 전복·고착 원인을 눈으로 확인할 때 씀.
나중에 Nav2 가 붙으면 RViz 의 "2D Goal Pose" 가 이 역할을 대체함.

### 평가 · 진단

```bash
cd sim/rl
# 학습에 쓰지 않은 경로 세트(seed 4321)에서 같은 스폰·흙 조건으로 짝비교
python3 compare_policy.py --model runs/s2/final --vecnorm runs/s2/vecnorm.pkl \
        --episodes 30
# 위 비교가 통과하면 같은 경로에서 구동·센싱 노이즈와 흙 랜덤화도 확인
python3 compare_policy.py --model runs/s2/final --vecnorm runs/s2/vecnorm.pkl \
        --episodes 30 --randomize

python3 eval.py --arena --terrain sand --episodes 30 \
        --model runs/foo/final --vecnorm runs/foo/vecnorm.pkl
python3 probe_teacher.py --model runs/foo/final --vecnorm runs/foo/vecnorm.pkl
tensorboard --logdir runs/foo/tb
```

`compare_policy.py` 는 순수 IK(잔차 0)와 학습 정책을 같은 시드로 실행하고,
완주율뿐 아니라 횡오차 평균·p90, 기수오차, 슬립, 시간, 잔차 사용률을 비교한다.
`runs/s2` 의 학습 경로 기본 seed 는 1234 이므로 평가 기본값 4321 과 다르다.
경로추종 보조라면 완주율만이 아니라 횡오차 평균·p90도 기준선보다 좋아져야 한다.
차체 기수오차는 기록하되, 게걸음·후진 중에는 경로추종 실패로 간주하지 않는다.
RViz/Nav2 브리지는 기본값에서 잔차 0(순수 IK)이고, `rl:=true` 일 때만 정책을
적용한다. 이 재생 평가는 Nav2 MPPI 명령과는 다른 pure pursuit 명령으로 잰 결과다.
브리지는 `/plan` 경로와 필터링된 Nav2 명령으로 정책 관측의 경로 관련 필드를
매 주기 채운다. 따라서 RViz 시험은 정책 적용 확인용이며, 성능 수치는 별도로 재야 한다.
현재 3D 잔차의 크기는 `config.py` 의 `d_vx_max/d_vy_max/d_om_max` 로 정해진다.
옛 `--clip-steer-deg`/`--clip-duty`는 현재 3D 행동에 영향이 없어서 제거했다.

---

## 설계상 중요한 선택

**정책은 기구학을 대체하지 않고 보정함.** 행동은 차체속도 잔차 3개
`(Δvx, Δvy, Δω)`이며, 기본 명령에 더한 뒤 공유 스워브 IK로 보낸다.
`config.py`의 `d_vx_max/d_vy_max/d_om_max`가 잔차 권한을 정한다.
RViz 주행에서는 `rl:=false` 또는 `/set_rl`로 잔차를 0으로 만들 수 있다.

**쿨롱 마찰로는 고착을 재현할 수 없음.** MuJoCo 기본 접촉은 미끄러지면 견인력이
`μN` 으로 고정이라 시뮬 로버가 자기 구덩이를 못 팜. 실제 모래는
`슬립↑ → 침하↑ → 저항↑ → 슬립↑` 의 양의 되먹임이 있고 그게 곧 고착임.
`terramech.py` 가 전단곡선을 마찰계수로 주고 침하를 상태로 적분해 재현함.

**기본 보상은 2026년 4WIS 논문의 진행·정렬·횡오차·헤딩오차·매끄러움 항목을
스워브에 맞게 변형한다.** 진행의 20%는 남기고, 80%는 횡오차와 **차체 헤딩**
게이트를 통과해야 받는다. 중앙으로 복귀하는 대각 이동을 벌주던 **실제 이동방향**
게이트는 제거했다. 경로 실거리 복귀는 할인 일치 잠재함수로 학습 신호를 주며,
같은 시간의 왕복 이동으로 점수를 만들 수 없다. 잔차 크기와 행동 2차 차분
벌점, 완주·전복·고착·경계 항도 유지한다. 보상 가중치는 `reward.py`의
`RewardCfg`에서 직접 수정한다.
최종 목표 기수는 Nav2의 도착 자세 제어가 맡는다.

**컨트롤러와 정책 관측은 측위 추정치를, 보상·판정은 참값을 씀.** `e_y`와
`e_psi` 관측도 pure pursuit와 같은 추정 자세에서 계산해 센서 랜덤화가 함께
적용된다. 실기에서는 이 자세를 Nav2 측위에서 공급해야 한다.

**측위 잡음은 저역통과로 줌**(τ=0.2 s). 50 Hz 백색잡음을 주면 조향이 지터를 따라
떨어 `scrub` 이 17배가 됨. 실제 측위는 EKF 가 오도메트리와 ICP(5~15 Hz)를 융합해
매끄러운 출력을 내므로 관측 잡음 대역이 제어 대역보다 훨씬 낮음.

**플래너 경사 상한은 현재 흙 모델의 견인력 가정에서 유도함.**
`max_slope_deg = 21.0°` 임. 규사 프리셋의 최대 마찰계수 0.55에서 침하 후
굴림·압밀 저항 약 0.14를 빼면 `atan(0.41) ≈ 22°`이며, 플래너에는 21°를 쓴다.
실제 규사의 마찰계수·침하 저항은 아직 측정하지 않았으므로 이는 실기 등판한계
측정값이 아니다. 30° 구간은 현재 Nav2 맵에서 통과 불가로 표시한다.

**학습 지형은 대회장 맵 고정 + 미세요철 교란임.** 거시 구조(램프·평지 배치)는
건축물이라 안 변하고, 변하는 것은 바퀴자국 규모(수 cm)임. 맵 하나에 고정하면 그
한 장의 요철까지 외우는데 모래는 대회 당일까지 움직임(다른 팀 주행·갈퀴질·습도).
암반 지형은 학습에서 빼고 일반화 검증용으로 남김.

**흙은 규사 하나로 고정하고 상태만 랜덤화함.** 대회장이 나무 프레임 위 규사 구조라
암석·경질토를 섞을 이유가 없음. 대신 다짐/습도(`μ` 0.60~0.82)와 두께(8~60 mm)를
난이도에 따라 흔듦.

**로버 형태는 랜덤화하지 않음.** 치수는 측정으로 확정되는 값이라 흔들 이유가 없음.
대신 실기에서 매 순간 변하고 측정으로 없앨 수 없는 것을 흔듦 — 배터리 전압(0.83~1.05),
엔코더 양자화·잡음, IMU 바이어스, 서보 지연·데드밴드, 제어 지연, 측위 오차.

---

## 학습 현황

항목별 전체 상태 표는 [루트 README](../README.md#현재-상태).

### `s3_path_reward` 검증 (2026-09-29)

아래 수치는 **경로 중간 스폰의 투영기 초기화와 로버 크기 이격을 고치기 전**의
기록이다. 현재 환경·Nav2 설정의 성능 수치가 아니며, 이 체크포인트를 새 환경의
평가 기준으로 재사용하지 않는다. 경로 수정 후·보상 수정 전 학습은
`runs/s4_route_fix`에 저장했고, 현재 보상의 새 학습은 `runs/s5_reward`를 쓴다.
100회는 서로 독립인 경로 100개가 아니라 고정된 경로 30개를 재사용했으므로,
표의 에피소드 단위 bootstrap 구간을 새 경로 전반의 불확실성으로 해석하지 않는다.

학습 경로 seed 1234와 다른 seed 4321의 규사 경로 30개에서, 같은 스폰·경로를
쓴 100 에피소드 짝비교 결과다. Stage 1과 같은 무잡음·비랜덤 물리,
pure pursuit 명령, 조향 대기 10° 조건이다. `4M`과 `18M`은 **같은 두 번째
학습 실행**의 체크포인트와 최종 모델이다. 첫 번째 실행은 약 246만 스텝에서
끝났고 같은 출력 폴더에 새 학습을 시작했으므로, 두 실행을 이어 학습한 것은 아니다.

| 지표 | 순수 IK | 4M 정책 | 18M 정책 |
|---|---:|---:|---:|
| 완주율 | 90% | 91% | 91% |
| 평균 횡오차 | 27.4 mm | 37.2 mm | 37.0 mm |
| 횡오차 p90 | 58.6 mm | 66.9 mm | 67.2 mm |
| 평균 슬립 | 0.18 | 0.24 | 0.23 |
| 잔차 평균 절댓값 | 0% | 77.8% | 84.2% |
| 차체 명령 포화 주기 | 6.1% | 23.0% | 31.1% |

18M의 순수 IK 대비 완주율 차이 `+1%p`의 짝 bootstrap 95% 구간은
`[-3, +5]%p`(RL만 3회, IK만 2회; McNemar exact `p=1.0`)라 개선 근거가 없다.
평균 횡오차 차이 `+9.6 mm`의 95% 구간은 `[+7.7, +11.5] mm`다.
학습 로그의 에피소드 보상 증가는 주로 `reward/smooth` 벌점이 약 `-26`에서
`-8`로 줄어든 데서 왔고, 4M→18M의 경로추종 개선으로 이어지지 않았다.
같은 미학습 경로의 앞 30쌍(seed 1000~1029)에서 18M 정책 행동에
`rl_scale=0, 0.25, 0.5, 1`을 곱해 확인한 평균 횡오차는 각각
`40.2, 41.7, 44.7, 50.3 mm`였다. 0.25배에서도 순수 IK보다
`+1.5 mm` 나빴다(짝 bootstrap 95% 구간 `[+0.3, +2.6] mm`).
따라서 현 정책은 출력만 줄여도 경로추종 개선 근거가 없으며, 무잡음 조건에서
먼저 실패하므로 노이즈·랜덤화 평가는 후순위다.
원인 진단용 20쌍에서는 **같은 보상식으로 계산한 총점도** 미학습 경로에서
순수 IK `319` 대 RL `275`, 학습 경로에서도 `336` 대 `308`이었다.
따라서 현재 보상식이 높은 횡오차를 더 좋게 평가해서만 생긴 결과는 아니다.
최종 정책 행동의 절댓값이 0.95를 넘는 주기 비율은 `vx/vy/ω` 각각
`69/73/62%`였고, 세 축 중 하나를 꺼도 순수 IK보다 횡오차가 컸다.
PPO 로그에서 `train/approx_kl` 중앙값은 첫 400만 스텝 `0.030`에서
마지막 구간 `0.244`로, `train/clip_fraction` 중앙값은 `0.18`에서
`0.48`로 커졌다. 잔차 상시 포화와 과한 정책 업데이트를 먼저 점검해야 한다.
이는 **Nav2 MPPI 주행 평가가 아니라** 학습과 같은 pure pursuit 명령을
미학습 경로에서 시험한 결과다. 기본 ROS launch의 `rl:=true`는 여전히
구형 `runs/s2` 모델을 지정하며 최신 체크포인트를 자동으로 고르지 않는다.

미확정 파라미터는 `config.py` 에 `[미정]` 으로 표시돼 있고 전부 도메인 랜덤화
범위로 덮여 있음.

### 알려진 제약

- **현재 규사 프리셋에서는 30° 램프를 못 오름.** `mu_max=0.55`, 기본 저항
  `c_r=0.05`라 침하 전부터 순견인 상한 0.50이 `tan(30°)=0.577`보다 작다.
  이는 미보정 흙 모델의 결과이며 실기 한계나 기구 변경 필요성을 입증하지 않는다.
- **`terramech.py` 가 `wheel_w` 를 쓰지 않음.** 바퀴 폭·접지압 효과를 정량화할 수 없음
- **`rollout/duty_sat`·`rollout/duty_use`는 현재 유효하지 않음.** `env.py`에서
  카운터를 0으로 초기화하지만 주행 중 갱신하지 않아 그래프가 0으로 남는다.
  잔차의 실현 한계는 우선 `rollout/cmd_sat`로 확인한다.
- **다리 하우징이 바퀴축 아래 30.35 mm 에 고정.** 지상고 9.6 mm 를 결정하는 값이고
  바퀴를 규정 한계(반경 58.25 mm)까지 키워도 지상고는 27.9 mm 가 상한임

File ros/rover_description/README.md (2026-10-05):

# Rover description — 실측 질량·전장·센서 반영

2026-10-04 22:28에 받은 `rover.f3z`를 기준으로 만든 ROS 2 URDF와 MuJoCo 모델입니다.
2026-10-05 수정: 카메라의 35도 하향 자세와 회전 후 무게중심을 반영했습니다.
추가 수정: 제공된 부품 형상 28개의 무게중심·관성을 닫힌 STL 부피 기준으로 계산했습니다.
각 부품 내부는 균일 밀도로 가정하고, 부품별 실측 질량에 맞췄습니다.
4륜 독립 조향·구동, 좌우 수동 로커의 1:1 반대 방향 연동을 유지합니다.
현재 합산 질량은 **2.3263 kg**이며 전선·커넥터와 추가 마운트는 포함하지 않습니다.

## 바로 사용할 파일

| 용도 | 파일 |
|---|---|
| ROS 2 패키지용 URDF | `urdf/rover.urdf` |
| 메시와 함께 직접 가져오기 | `rover_portable.urdf` |
| MuJoCo 실행·RL 환경의 출발점 | `mjcf/rover.xml` |
| 질량·관성·관절 제한·센서 프레임 | `config/model.json` |
| 부품별 실측 질량과 관성 | `config/components.json`, `config/component_masses.csv` |
| 부품 STL 관성 계산과 이전 근사 비교 | `config/mesh_inertia_audit.json` |
| 열린 면 보정·부피 합집합·볼록 형상 대체 기록 | `config/mesh_preparation_audit.json` |
| 스월브 조향축 간격과 모듈 좌표 | `config/swerve_geometry.json` |
| 조립 변환·전체 무게중심·외곽 치수 | `config/cad_reference.json` |
| 실제 검증 결과와 제한 사항 | `validation_report.json` |
| MuJoCo에서 렌더링한 확인 이미지 | `docs/mujoco_preview.png` |
| 카메라 하향 방향과 전체 무게중심 확인 | `docs/camera_35deg_com.png` |

메시는 이미 **m 단위**입니다. 가져올 때 추가 0.001 배율을 적용하지 마세요.
포터블 URDF는 `meshes` 폴더와 함께 보관해야 합니다.

## 링크와 좌표

`base_link`는 좌우 로커 회전축의 중앙이며 X 전방, Y 왼쪽, Z 위입니다.
Fusion CAD의 +Y가 전방입니다. CAD 글로벌 원점에 대한 `base_link` 위치는
`(0, 0, 161.813) mm`입니다.

CAD 좌표 `(X,Y,Z)` mm를 base_link 좌표로 바꾸면 `(Y,-X,Z-161.813)` mm입니다.

| 관절 | 부모 → 자식 | 로컬 축 |
|---|---|---|
| `left_rocker_joint` | 차체 → 왼쪽 로커 | `0 1 0` |
| `right_rocker_joint` | 차체 → 오른쪽 로커 | `0 1 0` |
| `{fl,fr,rl,rr}_steering_joint` | 로커 → 허브·구동 모터 | `0 0 1` |
| `{fl,fr,rl,rr}_wheel_joint` | 허브·구동 모터 → 휠 | `0 0 1` |

휠 관절 프레임의 회전으로 로컬 Z축을 실제 수평 휠 축에 맞췄습니다.
모든 휠의 양의 회전은 전진 방향입니다.
조향 모듈은 로커의 자식이므로 로커가 기울 때 조향축도 함께 기울어집니다.

### 스월브 기구학의 조향축 간격

로커 0 자세의 앞뒤 조향축 간격은 **204.862785 mm**, 좌우 간격은 **265.000 mm**입니다.
기구학에는 차체 외곽 폭이 아니라 아래 조향 피벗의 좌표를 사용합니다.
기준점은 `base_link`, X는 전방, Y는 왼쪽이며 단위는 m입니다.

| 모듈 | X | Y | Z |
|---|---:|---:|---:|
| FL 앞왼쪽 | +0.102431393 | +0.132500000 | -0.045313244 |
| FR 앞오른쪽 | +0.102431393 | -0.132500000 | -0.045313244 |
| RL 뒤왼쪽 | -0.102431393 | +0.132500000 | -0.045313244 |
| RR 뒤오른쪽 | -0.102431393 | -0.132500000 | -0.045313244 |

조향축은 서보 출력축–휠 허브 연결점이며, 그 수직 아래 구동축까지의 거리는
**69.000 mm**입니다. 구동축 기준점의 X/Y는 위 표와 같고 Z는 **-0.114313240 m**입니다.
기존 URDF `wheel_joint` 원점은 축 방향으로 바깥쪽 9.530 mm 이동한 점입니다.
두 점은 같은 구동 회전축 위에 있습니다. 두 좌표는 `config/swerve_geometry.json`과
`docs/joint_centers.md`에 함께 기록했습니다.

차체 속도 `(vx,vy)`와 yaw 각속도 `wz`에 대한 모듈 i의 평면 속도는
`vix = vx - wz*yi`, `viy = vy + wz*xi`입니다. 조향각은 `atan2(viy,vix)`,
휠 선속도는 `hypot(vix,viy)`로 계산합니다. 위 좌표는 전체 조립 좌표이며,
URDF의 조향 joint origin에 있는 로커 기준 로컬 좌표와 구분해야 합니다.
로커가 기울면 피벗 위치와 조향축 방향도 변하므로 3D 계산에서는 현재 관절각의
순기구학을 사용합니다. 고정 XY 좌표는 로커 수평 자세의 평면 근사입니다.

URDF에는 `q_right=-q_left` mimic 관계를 넣었습니다. MuJoCo MJCF에는 별도의
joint equality를 넣었으며 로커에 위치 제어 액추에이터를 달지 않았습니다.
내부 관절 10개 중 독립 자유도는 9개이며 조향·구동 8개만 능동 제어합니다.
고정 센서 프레임까지 포함하면 링크 22개, 관절 21개입니다.

## 센서

이번 F3Z 안의 IMU와 D435 부품은 제외했습니다. 별도로 받은 STL과 사용자가 지정한
원점을 사용하며 기존 CAD 센서의 회전·배치는 가져오지 않았습니다.

| 대상 | CAD 글로벌 STL 원점 (mm) | base_link 원점 (m) | 질량 |
|---|---|---|---:|
| D435 `camera_link` | `(0,116.619,157.691)` | `(0.116619,0,-0.004122)` | 72 g |
| IMU `imu_link` | `(0,0,137.213)` | `(0,0,-0.024600)` | 2.4 g |

IMU의 마지막 위치 수정인 Z축 -2.4 mm를 반영했습니다. IMU STL의 원점을 보존하고
native STL 축이 CAD 축과 같도록 배치했습니다. `imu_sensor_frame`은 현재 STL 원점과
같습니다. 실제 센서 칩 위치와 축 방향의 보정은 아직 실측하지 않았습니다.

D435는 +CAD Y 방향에서 수평보다 **35도 아래**를 바라보게 배치했습니다.
기존 STL 원점을 유지하고 `camera_link_joint`에 ROS Y축 +35도
(`rpy = 0 0.6108652381980153 0`)를 적용합니다. 카메라 메시, 충돌 형상,
관성 및 좌우 광학 프레임이 모두 함께 회전합니다. 사용자의 별도 STL은 폭 X,
높이 Y, 전면 +Z인 모델로 취급하고, 공식 모델의 메시 회전
`rpy=(pi/2,0,pi/2)`를 적용해 ROS 좌표에 맞췄습니다.

두 스테레오 카메라는 중앙 기준 좌우 25 mm, 간격 50 mm입니다.
전면판과 nominal zero-depth plane 사이의 4.3 mm는 전방 방향의 별도 오프셋입니다.

| 광학 프레임 | CAD 글로벌 원점 (mm) |
|---|---|
| `camera_infra1_optical_frame` — 왼쪽 | `(-25,113.096646,160.157379)` |
| `camera_infra2_optical_frame` — 오른쪽 | `(25,113.096646,160.157379)` |
| `camera_stereo_center_optical_frame` | `(0,113.096646,160.157379)` |

`camera_depth_optical_frame`은 공식 구성처럼 왼쪽 카메라 기준입니다.
광학 축은 X 오른쪽, Y 아래, Z 전방입니다. `camera_link`는 중앙 STL 원점이므로
공식 모델의 왼쪽 IR 기준 `camera_link`와 의미가 다릅니다.

D435의 좌우 영상은 흑백 센서 영상이며 RGB 카메라 두 개가 아닙니다.
패턴 프로젝터를 끄는 패시브 스테레오 구성을 전제로 했습니다.
URDF가 실제 장치의 emitter 설정을 바꾸지는 않습니다.
실기에서는 보정된 intrinsics/extrinsics를 우선하고 동일 이름의 TF를 중복 발행하지
않도록 URDF와 카메라 드라이버의 프레임 발행을 조정해야 합니다.

MuJoCo에 좌우 카메라 두 개와 IMU accelerometer/gyro를 넣었습니다.
시뮬레이터 카메라의 fovy=58도는 nominal 근사이며 실제 해상도·내부 파라미터를
보정한 값이 아닙니다. 스테레오 매칭이나 실제 깊이의 결측·노이즈 모델은 별도 작업입니다.

프레임 참고: https://github.com/realsenseai/realsense-ros/blob/ros2-master/realsense2_description/urdf/_d435.urdf.xacro

## 전장부와 질량

새 CAD의 조립 변환과 참조 부품을 추출했습니다. 배터리·보드·드라이버는 모두 차체에
고정된 하나의 강체로 합산했습니다. 조향 드라이버의 대체 모델은 따로 배치된
MDD3A occurrence 6734입니다. 두 구동 드라이버는 occurrence 5293과 5516입니다.

| 강체 묶음 | 질량 | 수량 |
|---|---:|---:|
| 차체 + 고정 전장 + 라지기어 | 791.9 g | 1 |
| 로커 + 서보 몸체 2개 + 스몰기어 | 186.2 g | 2 |
| 조향 허브 + 구동 모터 | 224.8 g | 4 |
| 휠 | 47.1 g | 4 |
| D435 | 72 g | 1 |
| IMU | 2.4 g | 1 |

몸체 408.5 g은 `773.1-15.6-349`이며 349 g은 이전 전장부입니다.
현재 전장부를 따로 합산하여 중복을 피했습니다.
조향 드라이버는 MDD3A 형상을 쓰면서 질량은 실측 12.9 g을 적용했습니다.
구동 MDD3A는 각각 20 g입니다. 라즈베리파이+AI HAT의 합산 질량 71.2 g은
라즈베리파이 모델에 모았으며 AI HAT의 별도 무게중심은 미측정입니다.

STM 보드는 F411RE CAD 대체 모델과 조립 변환을 사용합니다. 해당 F3D에는 표시용
삼각형 메시가 없어 MB1136의 70×82.5 mm 외형을 상자로 단순화했고, 원점 정렬과
20 mm 높이는 CAD mating origin을 이용한 근사입니다. 실제 MCU는 사용자의 F446RE입니다.
기준 치수: https://www.st.com/resource/en/user_manual/DM00105823.pdf

질량은 실측값입니다. 제공된 CAD/센서 형상 **28개를 부품별 STL로 분리**하고,
닫힌 부피의 무게중심·관성을 계산했습니다. `유효 밀도 = 실측 질량 / STL 부피`로
부품별 내부 균일 밀도를 적용합니다. 모든 부품에 같은 밀도를 넣은 것은 아니며,
전자부품·모터·센서 내부의 서로 다른 재료 분포는 의도적으로 무시합니다.
메시 28개의 폐곡면·일관된 면 방향·양의 부피를 확인했고, 실측 질량에 맞춘
부품 관성 텐서를 평행축 정리로 각 강체 링크에 합산했습니다.
질량은 g를 1000으로 나눈 kg, 길이는 m, 관성은 kg·m²입니다.
예를 들어 D435 72 g은 `<mass value="0.072"/>`입니다.

- 원본에서 이미 하나의 닫힌 입체인 15개는 그대로 사용했습니다.
- 나머지 13개는 분리된 입체의 합집합, 작은 구멍 보정, 기록된 내부 빈 공간 차감으로
  준비했습니다. 겹친 부피는 중복 합산하지 않습니다.
- 배터리·Pi·카메라·IMU의 일부 열린 셸은 볼록 형상으로 근사했습니다. 해당 셸 수,
  폐기한 평면 표시 조각, 보정 내역은 `mesh_preparation_audit.json`에 기록합니다.
- 일부 접촉 면의 겹친 정점은 STL 저장/재로드에서 비정상 연결을 만들기 때문에
  최대 0.000163 mm 분리했습니다. 부피·무게중심 변화가 수치 허용치 이내인지 확인했습니다.
- STM은 기존 상자 대체 모델을 STL로 저장해 계산한 것입니다. 실제 보드의 정밀
  STL로 바뀐 것은 아닙니다. Pi+AI HAT 질량도 여전히 Pi 대체 형상에 모았습니다.
- 실제 형상이 제공되지 않은 기어 3개는 기존 집중 질량·관성 근사를 유지합니다.

별도 관성용 STL은 `meshes/inertial_parts`에 포함합니다. CAD 부품 26개의 삼각형
추출 범위와 좌표 변환을 원본과 비교했고, 대응 좌표의 최대 오차는 30 nm 미만입니다.
원본 시각화 메시를 보존하고 `components.json`의 부품별 삼각형 범위로 재추출합니다.
관성 계산용 메시를 보정해도 시각화 메시와 충돌 형상은 바꾸지 않습니다.
구조물은 외곽 상자가 아닌 실제 벽·바닥·구멍 형상이 계산에 들어가지만, FDM의 인필과
외벽 간 밀도 차이는 STL에 없어 근사입니다. 유효 밀도는 PLA의 재료 밀도가 아닙니다.
URDF의 각 `inertial/origin`은 해당 링크의 로컬 무게중심이며, 전체 무게중심은
각 링크의 위치·자세를 적용한 질량 가중 평균입니다. 재생성 스크립트는
현재 카메라 자세까지 적용해 `cad_reference.json`을 자동 갱신합니다.
MuJoCo에는 질량과 관성을 명시하고 `inertiafromgeom="false"`로 설정하여
기본 밀도로 이 값들을 다시 추정하지 않도록 했습니다.
스몰기어는 각 로커 피벗, 라지기어는 차체의 로커축 중앙에 질량을 배분했습니다.
기어의 정확한 강체 소속·관성은 생략된 실제 기어 구조를 확인하면 개선할 수 있습니다.

## 검증 결과와 남은 조정

자동 검사 16개가 통과했습니다. 질량·관성·센서 자세·스테레오 프레임·부품 STL,
중첩 부피 합집합과 STL 저장/재로드를 검사합니다.
MuJoCo 3.14.0에서 다음을 실제 실행했습니다.

- 자유롭게 움직이는 차체, 능동 액추에이터 8개, 수동 로커 equality 1개로 모델 로드.
- 평지 정착 후 4륜 +2 rad/s 명령으로 1.5초 동안 약 0.141 m 전진.
- 왼쪽 로커에 외부 토크를 주었을 때 좌우가 같은 크기로 반대로 움직임.
- 왼쪽 앞 바퀴 아래 15 mm 단차에 정착하면서 로커가 반대 방향으로 기울어짐.
- 마찰계수 1.0인 강체 30도 경사에서 같은 명령으로 1.5초 동안 약 0.065 m 상승.
- 수치 경고 없음. 좌우 로커 각도 합의 최대 오차는 약 0.00039 rad 이하.

이 결과는 **설정한 강체 지면과 추정 액추에이터 조건의 기본 검증**입니다.
실제 모래의 30도 등판 성능을 입증하지 않습니다.
초기 충돌 형상은 부품별 상자와 러그 최대 반경을 포함한 휠 원통이며
MJCF에서는 로봇 내부 충돌을 껐습니다. 로봇–지면 접촉은 활성화되어 있습니다.

현재 부품별 균일 밀도 모델의 무게중심은 CAD 기준 `(-0.320,5.487,94.706) mm`입니다.
`base_link` 기준 ROS 좌표는 `(5.487,0.320,-67.107) mm`입니다.
차체 구조물 자체의 CAD 기준 무게중심 높이는 STL 부피 기준 127.933 mm이며,
부품 전체의 실측 질량 2.3263 kg은 유지했습니다. 이 값은 실측 무게중심이 아니라
제공된 형상과 기록된 근사에 따른 계산 결과입니다.
MuJoCo의 초기 자세 전체 무게중심과 URDF 질량 가중 계산값의 일치도 확인했습니다.
`camera_35deg_com.png`의 자홍색 점은 전체 무게중심이고, 빨간 화살표는
카메라의 하향 광학축입니다. 내부 점이 보이도록 차체만 투명하게 렌더링했습니다.
평지 휠 하중은 앞바퀴 각각 약 6.00~6.03 N, 뒷바퀴 각각 약 5.38~5.41 N입니다.
중력만 고려한 30도 경사의 균등 구동 토크는 바퀴당 약 0.136 N·m입니다.
이는 모래 저항·침하·가속·토크 여유를 포함하지 않습니다.

직진·로커 0 자세의 외곽은 길이 **297.72**, 폭 **302.19**, 높이 **181.81 mm**입니다.
폭이 300 mm 제한보다 **2.19 mm 큽니다**. CAD를 원본 치수로 보존했으며 자동 축소하지
않았습니다. 조향 시 외곽은 더 커질 수 있어 규정이 모든 조향 자세에 적용되는지도
확인해야 합니다. 제작 시 치수 조정과 공차 여유가 필요합니다.

학습 전에 실제로 맞추면 좋은 항목은 다음과 같습니다.

- 기계적 로커 제한과 조향 배선/간섭 제한. 현재 ±30도, ±90도는 초기 가정.
- 구동·조향 토크와 속도 제한, 마찰·댐핑, 저수준 제어 응답. 현재 초기 추정값.
- 최종 배선·커넥터·마운트를 포함한 실측 질량과 필요하면 센서 축/원점 보정.
- 사용할 지형과 접촉 모델. 모래 침하·슬립을 이 강체 모델만으로 재현하지는 못함.

ROS 2/RViz와 Isaac Sim에서의 실행은 이 환경에서 검증하지 않았습니다.
특히 다른 엔진에 URDF를 가져오면 mimic이 실제 수동 연동으로 작동하는지 확인해야 합니다.

## 사용

ROS 2 작업 공간의 `src/rover_description`에 이 폴더를 놓고:

```bash
colcon build --packages-select rover_description
source install/setup.bash
ros2 launch rover_description display.launch.py
```

MuJoCo에서는 포터블 URDF보다 **`mjcf/rover.xml`**을 사용하세요.
URDF 직접 로드는 루트를 고정하고 mimic/equality와 액추에이터를 자동으로 만들지 않습니다.
MJCF는 floating base, 로커 equality, 액추에이터와 센서를 포함합니다.
기본 중력은 지상 모사에 맞춘 9.81 m/s²입니다.

검증 및 재생성 스크립트는 Python, NumPy, SciPy, trimesh, vtk, mujoco,
manifold3d, networkx, pymeshfix를 사용합니다.
Python 3.12에서 검증했고 설치 명령은 다음과 같습니다.

```bash
python -m pip install -r requirements.txt
python -m mujoco.viewer --mjcf=mjcf/rover.xml
```

설정 파일을 수정한 뒤:

```bash
python scripts/prepare_component_meshes.py
python scripts/refine_mesh_inertia.py
python scripts/generate_urdf.py
python -m unittest discover -s scripts -p 'test_*.py' -v
python scripts/verify_physics.py
python scripts/render_preview.py
```

요구사항 테스트의 질량·센서 좌표는 이번 버전의 실측 입력을 검증합니다.
해당 입력을 새로 바꾼다면 테스트의 기대값도 새 요구사항에 맞춰 갱신해야 합니다.
URDF 재생성은 모델 설정의 질량·관성·관절값을 읽으며, 부품의 설치 위치를 바꿨다면
부품별 평행축 합산 및 메시 재배치도 함께 갱신해야 합니다.
`prepare_component_meshes.py`는 원본 시각화 STL에서 부품을 분리하고 닫힌 관성용
메시를 준비합니다. 이미 준비된 STL을 그대로 쓸 때는 이 단계를 생략할 수 있습니다.
`refine_mesh_inertia.py`는 부품별 STL과 실측 질량을 읽어 링크 관성을 합산합니다.
설치 위치나 형상을 바꾼 경우 관성용 부품 STL도 해당 링크 좌표에 맞춰 갱신하세요.
이 스크립트를 실행하면 직접 입력한 링크 관성은 부품 계산값으로 갱신됩니다.

`docs/build_sources`에는 이번 CAD 추출/조합 과정의 소스 코드를 보관했습니다.
이 소스는 원본 F3Z를 풀어 만든 중간 폴더와 이전 CAD 검사 결과를 입력으로 사용하며,
위 `scripts/generate_urdf.py`는 완성 패키지의 설정 파일만으로 실행할 수 있습니다.
보관된 CAD 조합 소스는 초기 부품 상자 근사 단계의 기록입니다. 최종 STL 관성
개선은 `scripts/prepare_component_meshes.py`, `scripts/refine_mesh_inertia.py`와
포함된 메시/설정 파일로 재현합니다.

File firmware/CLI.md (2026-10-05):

# 펌웨어 CLI

빌드·플래시, 터미널 명령, 세팅 절차를 모은 문서. 설정값의 의미와 위치는
[README.md](README.md) 가 정본이다.

---

## 1. 빌드 / 플래시 (PC)

```bash
cd ~/ksrc/firmware/src2026-rover-firmware

./build.sh              # 빌드만
./build.sh --flash      # 빌드 후 ST-Link 로 플래시 (보드 USB 연결)
./build.sh --clean      # build/ 지우고 전체 재빌드
```

- `arm-none-eabi-gcc` 가 PATH 에 없으면 CubeIDE 에 들어 있는 툴체인을 자동으로 찾는다.
- **코드를 고쳤으면 `--flash` 까지** 해야 보드에 반영된다. `./build.sh` 만으로는 안 바뀐다.
- `common/*.c` 를 고쳤으면 시뮬 라이브러리도 다시 빌드: `bash ~/ksrc/sim/build.sh`
- 플래시와 터미널은 같은 USB 포트(`/dev/ttyACM0`)를 쓴다. 터미널을 열어 둔 채로는
  플래시가 실패하므로 먼저 닫는다.

---

## 2. 시리얼 터미널 (PC)

```bash
python3 -m serial.tools.miniterm /dev/ttyACM0 115200
```

나가기: `Ctrl+]`. 대소문자 구분 없음, 한 줄 입력 후 엔터.

**시작하면 먼저 `LOG`** 를 친다. 기본 상태에서는 엔코더 로그가 0.1초마다 쏟아져서
명령 응답이 묻힌다. 텔레옵(첫 `V`)이 시작되면 로그와 에코는 자동으로 꺼진다.

USB 만 꽂으면 STM32 만 켜진다. 모터·서보는 12V 별도 전원이 있어야 움직인다.

---

## 3. 터미널 명령

### 화면

| 명령 | 설명 |
|---|---|
| `LOG` | 주기 로그 on/off 토글. 부팅 시 ON, 텔레옵 시작 시 자동 OFF |
| `ECHO` | 입력 에코 on/off 토글 (백스페이스 수정 가능) |
| `HELP` | 명령 목록 |

### 조향 서보

| 명령 | 설명 |
|---|---|
| `PING` | 서보 ID 1~4 응답 확인 |
| `SCAN` | ID 1~253 전체 스캔 (약 1초) |
| `ID <현재> <새>` | 서보 ID 변경. **서보 1개만 연결한 상태에서**. `254` = 브로드캐스트 |
| `ZERO <id\|ALL>` | 현재 자세를 0° 로 서보 EEPROM 에 기록 |
| `ON` / `OFF` | 토크 켜기 / 끄기 (끄면 손으로 돌릴 수 있음) |
| `T <a1> <a2> <a3> <a4>` | 조향각 직접 지정 (도). **서보 번호 순서 = LF, LB, RF, RB**. 준 개수만큼만 보냄. 가동범위(±100°)로 클램프 |
| `P` | 현재 조향각 읽기 |
| `S <step/s>` | 서보 최고속 제한. `0` = 최대(기본). 4096 step = 360° → `S 1500` ≈ 132°/s. 재부팅 시 0 |

### 구동 / 주행

| 명령 | 설명 |
|---|---|
| `V <vx> <vy> <ω>` | 차체 속도 (m/s, m/s, rad/s). x=전진, y=좌측, ω 반시계 +. **첫 `V` 에서 텔레옵 시작** (되돌리려면 리셋) |
| `MOT <1-4\|ALL> <duty> <ms>` | 구동모터 하나를 날 부호로 돌리고 엔코더 변화·rpm 출력. duty -799~+799, ms 50~3000 (**2000 이하 권장**, 16비트 엔코더 한계). 텔레옵 전에만. 도는 동안 로그 멈춤 |
| `MTEST` | 모터 자가시험 시퀀스 on/off (기본 OFF). 1→4번 정/역 2초씩. 텔레옵 전에만 |
| `GATE` | 구동 정렬 게이트 on/off (기본 ON). 서보 없이 구동만 시험할 때 끈다 |
| `CTRL [ON\|OFF]` | 텔레옵 중 5Hz 상태줄: `[CTRL] v vx vy ω \| deg 조향각×4 \| duty ×4` (+ `GATE`, `WDOG`). 받은 명령 확인용. 인자 없으면 토글. `LOG` 와 별개라 텔레옵 시작 후에도 유지 |
| `SPI` | Pi SPI 링크 진단: `CS에지`(프레임 끝으로 인정한 CS 상승) `잡음`(무시한 CS 스파이크) `완전/짧음` 프레임 수, 마지막 수신 바이트 수·첫 두 바이트(정상 `A5 5A`), 파싱오류, 현재 PB12/PB13 레벨(Pi 유휴면 1/0). Pi 에서 보내기 전·후로 한 번씩 쳐서 비교 |

`V` 동작:
- 50Hz 제어주기가 출력한다 (명령은 목표값만 바꾼다).
- 500 ms 동안 명령이 없으면 정지 (조향각은 유지).
- 조향이 60° 넘게 바뀌면 바퀴가 10° 안에 정렬될 때까지 구동 0 (최대 1.5초).

---

## 4. 세팅 절차

### 4.1 처음 배선 후 (서보 ID)

```
LOG
SCAN                      버스에 몇 번으로 잡히는지
```

ID 를 새로 줄 때는 서보를 **하나씩만** 연결한다.
```
ID 254 4                  연결된 1개를 4번으로 -> 분리하고 다음 서보
ID 254 3
ID 254 2
ID 254 1
SCAN                      4개 전부 연결 후 1~4 확인
```

### 4.2 조향 영점 (조립 완료 후, Z1)

```
OFF                       토크 해제
                          -> 네 바퀴를 손으로 정면 정렬 (자/직선 기준, 구동모터는 몸체 안쪽)
ZERO ALL                  지금 자세를 0° 로 EEPROM 기록
ON
T 0 0 0 0                 네 바퀴 모두 정면이면 성공
```

### 4.3 조향 방향 (Z2)

```
T 30                      서보1 (LF)
T 0 30                    서보2 (LB)
T 0 0 30                  서보3 (RF)
T 0 0 0 30                서보4 (RB)
T 0 0 0 0
```
각각 **위에서 볼 때 반시계**면 정상. 시계로 돈 서보는
`src2026-rover-firmware/Core/Src/joint.c` 의 그 서보 `.dir = -1` → `./build.sh --flash` → 다시 확인.

### 4.4 가동범위 (Z3)

```
T 60   / T -60            서보1 을 천천히 키워 가며
T 90   / T -90
T 100  / T -100           구동모터·배선이 몸체에 닿는지
T 0
```
다른 서보는 `T 0 90`, `T 0 0 90`, `T 0 0 0 90` 처럼 자리만 바꾼다.
간섭이 있으면 `joint.c` `.min_deg/.max_deg` **와** `sim/rl/config.py`
`steer_lo_deg/steer_hi_deg` (순서 FL, FR, RL, RR) 를 같이 고친다. 폭은 180° 이상 유지.

### 4.5 구동모터 (바퀴 띄우고, Z4~Z6)

```
LOG                       (로그가 켜져 있으면 끄기 -- MOT 결과 줄이 묻힌다)
MOT 1 300 1000            모터1: 어느 바퀴가, 어느 방향으로 도는지 + 엔코더 부호
MOT 2 300 1000
MOT 3 300 1000
MOT 4 300 1000
MOT 1 799 2000            무부하 rpm (정격 약 76 rpm)
```
- 엉뚱한 바퀴가 돌면 `main.c` `SWERVE_MODULE_MOTOR` 수정
- 그다음 `V 0.05 0 0` 으로 확인: 뒤로 도는 바퀴의 모터 → `MOTOR_DRIVE_SIGN = -1`
- 전진하는데 `LOG` m/s 가 음수인 모터 → `ENCODER_SIGN = -1`
- 고친 뒤 `./build.sh --flash`

### 4.6 조향 속도 (선택)

```
S 1500                    ~132°/s 로 제한 (S 0 = 최대)
```
마음에 드는 값을 찾으면 `joint.c` 의 `joint_goal_speed` 기본값으로 넣는다.

---

## 5. 조이스틱 주행 (PC, USB 직결)

```bash
# miniterm 은 먼저 닫는다 (포트는 한 프로그램만 연다)
cd ~/ksrc
python3 pi/teleop/teleop_joystick.py --port /dev/ttyACM0 --max-lin 0.15 --max-ang 0.8
```

| 인자 | 기본값 | 설명 |
|---|---|---|
| `--port` | `/dev/ttyACM0` | STM32 USB 포트 |
| `--rate` | 20 | 전송 Hz (30 이상이면 파서가 바이트를 흘림) |
| `--max-lin` | 0.5 | 패드 끝 = 이 속도 (m/s). 실제 최고 0.318 이라 처음엔 0.15 권장 |
| `--max-ang` | 2.0 | 패드 끝 = 이 각속도 (rad/s) |
| `--monitor` | 끔 | STM 에 `CTRL ON` 을 보내고, 보낸 값(`PC >`)과 STM 이 받은 값(`STM>`)을 터미널에 나란히 출력 |
| `--deadzone` | 0.1 | 패드 중심 데드존 (반경 비율). 중심 손떨림이 바퀴를 홱홱 돌리지 않게 |
| `--snap-deg` | 10 | 앞·뒤·좌·우에서 이 각도 이내면 축으로 맞춤. 횡걸음 중 손떨림으로 조향이 87°↔93° 떠는 것 제거 |
| `--hold-mag` | 0.35 | 이 크기 미만에서는 바퀴 축을 `--hold-deg` 넘게 바꾸는 방향을 0 으로 보냄 (조향 유지) |
| `--hold-deg` | 20 | 위 저속 구간에서 허용하는 바퀴 축 변화. **정반대 방향(우↔좌, 전↔후)은 항상 허용** |

조작: 왼쪽 패드 = 병진, 오른쪽 패드 또는 `Q`/`E` = 회전, `Space` = 정지, `Esc` = 종료.

STM 이 vx, vy, ω 를 제대로 받는지 확인 (케이블 하나로, miniterm 없이):
```bash
python3 pi/teleop/teleop_joystick.py --port /dev/ttyACM0 --max-lin 0.15 --max-ang 0.8 --monitor
```
```
PC > v +0.150 +0.000 +0.000
STM> [CTRL] v +0.150 +0.000 +0.000 | deg 0 0 0 0 | duty 376 376 376 376
```
`PC >` 와 `STM>` 의 v 가 같으면 정상. 조이스틱은 패드를 안 움직여도 0 을 20Hz 로 보내므로
`STM>` 줄은 켜자마자 나온다. 안 나오면 펌웨어가 `CTRL` 명령이 없는 이전 버전이다
(`./build.sh --flash`). 정렬 대기 중이면 줄 끝에 `GATE`, 명령이 끊기면 `WDOG` 가 붙는다.

**저속 방향 고정이 하는 일:** 우 횡걸음 → 좌 횡걸음처럼 패드를 반대편으로 옮길 때, 마우스가
중앙을 위·아래로 스쳐도 그 사이의 "전진/후진" 성분이 나가지 않는다. 그래서 바퀴는 90° 를 유지하고
구동만 반전된다 (이전에는 경로에 따라 네 바퀴가 0° 쪽으로 돌았다 오며 최대 약 300° 를 돌았다).
대신 횡걸음 → 전진처럼 **바퀴 축을 바꾸는 방향 전환은 패드를 35% 넘게 밀어야** 시작된다.
작게만 밀면 바퀴는 제자리에 서 있는다.
처음에는 **바퀴를 띄운 상태**로 네 바퀴 방향부터 확인한다 (4.5).

---

## 6. Pi 에서 SPI 링크 확인

Pi 접속: `ssh pi@raspberrypi.local` (같은 Wi-Fi). Pi 는 Ubuntu 24.04 호스트이고,
ROS 2 는 `docker exec -it humble_rover bash` 안에 있다.

처음 한 번 (sudo 비밀번호 필요):
```bash
sudo apt install -y python3-spidev
sudo usermod -aG dialout pi      # /dev/spidev0.0 이 dialout 그룹. 재접속 후 적용
```

배선: Nucleo PB12 (CN10-16) → Pi 핀24 (CE0), PB13 (CN10-30) → 핀23 (SCLK),
PC2 (CN7-35) → 핀21 (MISO), PC3 (CN7-37) → 핀19 (MOSI),
그리고 **Pi 핀25 (GND) → Nucleo GND 직결선** (모터 GND 묶음과 별도).
**SCLK 선은 MOSI·MISO 와 떼어서** (가능하면 GND 선과 나란히) 보낸다. 묶어 두면 크로스토크로
가짜 클럭이 생겨 프레임이 전부 깨진다 (2026-10-05 실측, 속도를 낮춰도 안 없어짐). MISO·MOSI 는 묶어도 됨.

```bash
cd ~/ksrc
python3 pi/common/spi_monitor.py               # 수신만 (명령 안 보냄)
python3 pi/common/spi_monitor.py --vx 0.05     # 전진 명령
python3 pi/common/spi_monitor.py --vy 0.05     # 게걸음
python3 pi/common/spi_monitor.py --w 0.5       # 제자리 회전
```
`[BAD]` 만 나오면 배선·CE0·GND 확인. 출력 태그 `W` = 워치독, `G` = 게이트 대기,
`T` = 게이트 타임아웃. `enc[...]` = 엔코더 누적 틱 (FL FR RL RR, 바퀴 1회전 8384).

**`[BAD]` 원인 좁히기** (시리얼 `SPI` 명령과 같이):
```bash
# Pi: 정확히 10바이트(클럭 80번)만 보낸다
python3 -c "import spidev;s=spidev.SpiDev();s.open(0,0);s.mode=0;s.max_speed_hz=10000;s.xfer2([0xA5,0x5A,1,2,3,4,5,6,7,8])"
```
그다음 miniterm 에서 `SPI` → `마지막 N바이트 첫 XX XX`:
`10바이트 A5 5A` 정상 / `11바이트 이상` = SCLK 링잉(선 분리·GND·직렬저항) /
`CS에지 0` = CE0 선 / `0바이트` = SCLK 선 / `10바이트인데 다른 값` = MOSI 선.

### IMU 확인
```bash
python3 pi/common/imu_check.py      # 2초 정지 보정 후 10Hz: acc, |acc|, roll/pitch, gyro, 자이로 적분각
```
값은 **로버 좌표** (x 전진, y 좌측, z 위). 칩→로버 변환은 `pi/common/nucleo_link.py`
`IMU_CHIP_TO_BODY` (현재 칩이 z 기준 180° 장착 → x, y 반대). 정상: 정지 시 acc ≈ 0 0 +1,
반시계 90° → 셋째 누적 ≈ +90, 앞을 숙이면 pitch +. Enter = 누적각 리셋.

### 조이스틱 주행 (PC 창 → 라파 → SPI)
라파는 화면이 없고, ssh X 포워딩(`-X`/`-Y`)으로는 pygame 창이 MIT-SHM 오류로 안 뜬다.
그래서 **창은 PC**, **Nucleo 통신은 라파**가 맡는다. PC 와 라파는 같은 와이파이.
```bash
# 1) 라파 (ssh pi@raspberrypi.local)
cd ~/ksrc && git pull
python3 pi/common/udp_spi_bridge.py          # UDP 5005 -> SPI 50Hz 중계

# 2) PC (새 터미널)
cd ~/ksrc
python3 pi/teleop/teleop_joystick.py --udp raspberrypi.local --rate 50 --max-lin 0.15 --max-ang 0.8 --monitor
```
조작·인자는 5 와 같다. `--monitor` 의 `STM>` 줄과 창 아래 초록 줄은 라파가 돌려주는 텔레메트리
(STM 이 실제 적용한 v, 조향각, duty). 라파 화면에는 `[PC주소] 보냄 v ... rx= drop= crc_bad=` 가 0.5초마다.
안전: PC 명령이 0.3초 끊기면 라파가 0 을 보내고(`끊김->0`), 라파까지 끊기면 STM 워치독(500ms)이 정지.
라파는 받은 값을 `--max-lin 0.32 --max-ang 2.0` 으로 한 번 더 자른다.

---

## 7. 자주 겪는 것

| 증상 | 원인 / 해결 |
|---|---|
| 플래시 실패, 포트 열기 실패 | 다른 프로그램(miniterm, 조이스틱)이 `/dev/ttyACM0` 을 잡고 있음 |
| `No debug probe detected` | ST-Link 인식 안 됨. `lsusb \| grep 0483`. 충전 전용 USB 케이블 의심 |
| 명령을 쳐도 안 움직임 | 12V 전원 확인. USB 는 STM32 만 켠다 |
| `MOT` 가 거부됨 | 이미 `V` 로 텔레옵이 시작됨 → 보드 리셋 |
| `MOT` 결과가 안 보임 | `LOG` 로 로그 끄기. 도는 동안은 로그가 멈추는 게 정상 |
| `MOT` 엔코더 0 | 12V·엔코더 배선 확인, 또는 duty 가 너무 작아 기동 못 함 |
| 바퀴가 안 돌고 1.5초씩 멈춤 | 정렬 게이트가 서보 각을 못 읽음 (서보 전원/배선). 서보 없이 시험할 땐 `GATE` |
| `PING` 전부 FAIL | 서보 12V·PB10 배선·ID 확인 |
| `IMU ... 응답 없음` (부팅 메시지) | SPI3 배선, CS = PC9 확인. 1초마다 재시도함 |
| Pi `[BAD]` 계속 / `SPI` 파싱오류 증가 | SCLK 선을 MOSI·MISO 와 분리, Pi 핀25 GND 직결 (6 참고) |
| IMU 세 축이 같은 값 / 가끔 튐 | SPI3 잡음. 펌웨어가 즉시 무효 처리·재설정. 잦으면 PC10(SCK) 선 분리 |
| 조이스틱 `STM>` 가 안 나옴 (--udp) | 라파에서 `udp_spi_bridge.py` 실행 중인지, 같은 와이파이인지 |
| 조향이 너무 빠름 | `S 1500` 등으로 제한 |

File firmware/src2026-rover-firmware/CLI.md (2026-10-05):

# CLI 레퍼런스

로버 펌웨어를 빌드·플래시하고, 시리얼 터미널로 조작하는 방법.

---

## 1. PC에서 실행하는 명령

### 빌드 / 플래시

```bash
cd ~/ksrc/firmware/src2026-rover-firmware

./build.sh              # 빌드만
./build.sh --flash      # 빌드 후 ST-Link로 플래시
./build.sh --clean      # build/ 지우고 전체 재빌드
```

`arm-none-eabi-gcc`가 PATH에 없으면 CubeIDE에 번들된 툴체인을 자동으로 찾습니다. CubeIDE를 열 필요 없습니다.

### 시리얼 터미널

```bash
python3 -m serial.tools.miniterm /dev/ttyACM0 115200
```

나가기: `Ctrl+]`

ST-Link의 가상 COM 포트입니다. 보드와 PC를 잇는 USB 케이블 하나가 **플래시와 터미널 둘 다** 담당합니다.

### 조이스틱 텔레오퍼레이션

```bash
python3 ~/ksrc/pi/teleop/teleop_joystick.py
```

| 인자 | 기본값 | 설명 |
|---|---|---|
| `--port` | `/dev/ttyACM0` | 시리얼 장치 |
| `--baud` | `115200` | 보레이트 |
| `--rate` | `20.0` | 명령 전송 주기(Hz). 30 넘기면 펌웨어 파서가 바이트를 흘리기 시작 |
| `--format` | `ascii` | `ascii`=실제 로버(`V ...` 줄), `binary`=시뮬레이터 |
| `--max-lin` | `0.5` | 패드 최대 변위에 대응하는 \|vx\|,\|vy\| (m/s) |
| `--max-ang` | `2.0` | 패드 최대 변위에 대응하는 \|ω\| (rad/s) |

조작: 왼쪽 패드 드래그=병진, 오른쪽 패드=회전, `Q`/`E`=회전(병진과 동시 가능), `Space`=정지, `Esc`=종료.

시뮬레이터에 붙일 때만 `--format binary`를 씁니다.

---

## 2. 터미널 명령어

대소문자 구분 없음. 한 줄 입력 후 엔터.

### 화면 / 도움말

| 명령 | 인자 | 설명 |
|---|---|---|
| `LOG` | 없음 | 주기 로그 + 모터 테스트 단계 메시지 + 제어주기 상태줄 on/off **토글**. 기본 ON, **텔레옵이 시작되면 자동 OFF** |
| `ECHO` | 없음 | 입력 문자 에코 on/off **토글**. 기본 ON |
| `HELP` | 없음 | 명령 목록 |

> **작업 시작할 때 `LOG` 한 번** 치고 시작하세요. 기본 상태에서는 엔코더 로그가 0.1초마다 5줄씩 쏟아져 입력도 응답도 읽을 수 없습니다. `LOG`를 끄면 완전히 무음이 되고, 내가 친 글자와 명령 응답만 보입니다. 토글이라 리셋 전까지 유지됩니다.

**에코**: 펌웨어가 받은 문자를 되돌려 보내므로 타이핑이 그대로 화면에 보이고, **백스페이스로 오타를 고칠 수 있습니다**. 터미널 프로그램(miniterm / screen / PuTTY)과 무관하게 동작합니다. 터미널 자체의 로컬 에코를 쓰고 있어 글자가 두 번 보인다면 `ECHO`로 끄세요.

> 텔레옵(`V` 명령)이 시작되면 에코는 **자동으로 꺼집니다.** 조이스틱이 초당 수백 문자를 보내는 동안 ISR 이 송신을 기다리면 수신 오버런이 나기 때문입니다.

### 서보 탐색 / 설정

| 명령 | 인자 | 설명 |
|---|---|---|
| `PING` | 없음 | ID 1~4 응답 확인 |
| `SCAN` | 없음 | ID 1~253 전체 스캔. 약 1초, 실행 중 모터 정지 |
| `ID <현재> <새>` | 현재 0~254, 새 0~253 | 서보 ID 변경 |
| `ZERO <id\|ALL>` | id 1~253 또는 `ALL` | 현재 자세를 0도로 영점 기록 |

**`ID` 주의**: 반드시 **서보를 1개만 연결한 상태**에서 실행하세요. 여러 개가 물린 채로 하면 전부 같은 ID가 됩니다. `254`는 브로드캐스트라 현재 ID를 몰라도 됩니다 — `ID 254 3`.

**`ZERO` 주의**: 서보 EEPROM에 기록되어 전원을 꺼도 유지됩니다. 실행 전에 `OFF`로 토크를 풀고 바퀴를 물리적으로 정면 정렬해야 합니다.

### 조향 제어

| 명령 | 인자 | 설명 |
|---|---|---|
| `ON` / `OFF` | 없음 | 토크 켜기 / 끄기. 끄면 손으로 돌릴 수 있음 |
| `T <a1> <a2> <a3> <a4>` | 각도(도), 최대 4개 | 조향각 직접 지정. 준 개수만큼만 전송 |
| `P` | 없음 | 현재 조향각 읽기 |
| `S <속도>` | 정수, step/s | 서보 이동 속도. `0`=최대 |
| `GATE` | 없음 | 구동 정렬 게이트 on/off **토글**. 기본 ON. 서보를 떼고 구동모터만 시험할 때 끈다 |
| `MTEST` | 없음 | 모터 자가시험 on/off **토글**. **기본 OFF**. 모터를 하나씩 정/역 2초씩 돌린다 (바퀴 띄우고). 텔레옵 전에만 |

`T`는 인자 개수만큼만 명령을 보냅니다 — `T 30`은 1번 서보에만, `T 0 30`은 1·2번에만. 각도는 `joint.c`의 서보별 `min_deg`/`max_deg`(현재 전부 ±100°)로 클램프되고, 잘리면 경고가 한 줄 나옵니다.

`T`의 인자 순서는 **서보 ID 순서**입니다. 바퀴 배치는 다음과 같습니다.

```
서보1 (LF)   서보3 (RF)
서보2 (LB)   서보4 (RB)
```

기구학 모듈 순서(FL, FR, RL, RR)와 다릅니다. 변환은 `main.c`의 `SWERVE_MODULE_SERVO[]` 한 곳에서만 합니다.

### 조향 가동범위 (바퀴별)

`joint.c`의 `joint_config[].min_deg/max_deg`가 **유일한 정본**입니다. 기구학(`swerve_fold_to_range`)이 매 제어주기 이 값을 읽어서, 목표 방향의 등가각(θ, θ±180°) 중 범위 안에 있으면서 직전 각에 가장 가까운 것을 고릅니다. 바퀴마다 값이 달라도 됩니다.

- 폭(`max - min`)이 **180° 이상**이어야 모든 방향을 낼 수 있습니다. 더 좁으면 일부 방향은 경계로 잘립니다.
- 폭이 딱 180°이면 방향마다 쓸 수 있는 각이 하나뿐이라 경계를 지날 때마다 180° 반전이 생깁니다. 반전 중에는 정렬 게이트가 구동을 멈춥니다.
- 정하는 순서: `OFF` → 바퀴 정면 정렬 → `ZERO ALL` → `ON` → `T`로 한 바퀴씩 돌려 부호(`dir`)와 간섭 각을 확인 → `min_deg/max_deg` 수정 → 재빌드.

### 기구학 주행

| 명령 | 인자 | 설명 |
|---|---|---|
| `V <vx> <vy> <ω>` | **정확히 3개** | 몸체 속도 → 4모듈 조향각+구동 duty 자동 계산 |

좌표계: **x=전진, y=좌측, ω=반시계(+)**. 단위는 m/s, m/s, rad/s.

```
V 0.1 0 0      전진
V 0 0.1 0      왼쪽 게걸음
V 0 0 1.5      제자리 반시계 회전
V 0 0 0        정지
```

동작 특성:
- **첫 구동 명령(`V` 또는 SPI)에서 텔레옵이 시작**되고 에코·로그가 꺼지며, `MTEST`가 켜져 있었다면 멈춥니다. 되돌리려면 보드 리셋. 모터 자가시험은 **기본 OFF**라 전원을 넣어도 바퀴가 스스로 돌지 않습니다.
- **50Hz 고정 제어주기**: `V`는 목표 속도만 바꾸고, IK·조향·PWM은 20ms마다 한 번씩 나갑니다(시뮬과 같은 주기). 명령이 몇 Hz로 오든 출력 주기는 같습니다.
- **구동 정렬 게이트**: 다음 중 하나면 네 바퀴의 **실제** 조향각이 목표의 10° 안에 들 때까지 구동을 0으로 둡니다.
  - 목표 조향각이 한 주기에 60° 넘게 바뀜 (큰 방향 전환, 180° 반전)
  - 구동 중 목표와 실제 조향각 차이가 60° 넘음 (조금씩 돌려서 위 조건을 피한 경우)
  - 텔레옵 후 첫 구동
  
  **1.5초** 안에 정렬되지 않으면(모래에서 정지 조향 막힘, 기구 간섭, 서보 무응답) 강제로 풀고 텔레메트리 `GATE_TIMEOUT`을 세웁니다. 서보 없이 벤치 시험할 때는 매번 1.5초씩 기다리게 되므로 `GATE`로 끄는 게 편합니다.
- **워치독**: 마지막 구동 명령 이후 500ms 동안 명령이 없으면 목표 속도를 0으로 둡니다(조향각은 유지). 조이스틱이나 Pi가 끊겨도 로버가 계속 굴러가지 않도록 하는 안전장치입니다.
- 제어주기 상태줄(`[CTRL] deg ... duty ...`)은 `LOG`가 켜져 있을 때만 5Hz로 나옵니다. 텔레옵이 시작되면 LOG는 자동으로 꺼집니다. 다시 켜면 10Hz 엔코더 로그가 한 번에 약 30ms 동안 UART 송신으로 루프를 막아 **50Hz 제어주기가 흔들립니다** (디버깅할 때만).

---

### Pi SPI 링크 (SPI2 슬레이브)

Pi가 SPI 마스터이고 Nucleo SPI2가 슬레이브입니다. 한 번의 전송(CS low → 144바이트 → CS high)에서 Pi는 속도 명령을 보내고 동시에 Nucleo의 텔레메트리를 받습니다. 프레임 레이아웃의 정본은 `firmware/common/spi_link.h`, Pi 쪽 구현은 `pi/common/nucleo_link.py`(`SpiLink`)입니다.

| Nucleo 핀 | 신호 | Pi 5 |
|---|---|---|
| PB12 | SPI2_NSS | CE0 (GPIO8, 핀 24) |
| PB13 | SPI2_SCK | SCLK (GPIO11, 핀 23) |
| PC2 | SPI2_MISO | MISO (GPIO9, 핀 21) |
| PC3 | SPI2_MOSI | MOSI (GPIO10, 핀 19) |
| GND | | GND |

- 모드 0, 8비트, **1MHz 권장**. Nucleo가 HSI 16MHz로 돌아서 8MHz가 절대 상한입니다.
- 항상 144바이트(프레임 v2)를 한 번의 CS 구간으로 보냅니다. 길이가 다르면 Nucleo가 그 전송을 버리고 다음 CS에서 다시 맞춥니다.
- 텔레메트리는 50Hz 제어주기마다 갱신됩니다. 명령 워치독이 있으므로 Pi는 최소 10Hz 이상, 보통 50Hz로 교환합니다.
- 텔레메트리 필드(모두 같은 50Hz 제어주기 시각 `t_ms`에 샘플). 배열은 모듈 순서 FL, FR, RL, RR입니다.
  - 구동: 적용 명령, 누적 엔코더 틱, 바퀴 속도, duty
  - 조향 서보(STS3215): 목표각, **실측 각·속도·부하·전압·온도·상태**, 모듈별 유효 비트 `servo_valid`
  - IMU(ISM330DHCX, SPI3): 자이로·가속도 원시값(센서 좌표계, ±500dps / ±4g), `IMU_VALID` 플래그
  - 상태 플래그: 워치독, 게이트 대기, 서보 읽기 실패, 조향 클램프, 명령 출처
- 서보 4개 읽기는 매 주기 약 3ms입니다. 응답 없는 서보는 0.5초 동안 건너뛰고 다시 시도합니다(타임아웃 15ms가 매 주기 반복되지 않게).
- IMU는 부팅 시 WHO_AM_I(0x6B)를 확인하고, 1초마다 다시 확인합니다. 끊겼으면 재초기화를 시도합니다.
- Pi에서 확인: `python3 pi/common/spi_monitor.py` (폴링만), `--vx 0.05` (명령 전송).
- UART `V`와 SPI 명령은 같은 목표값을 씁니다. 마지막에 온 명령이 이깁니다.
- `rover_motor.ioc`에 SPI2·SPI3가 들어가 있지만 **CubeMX가 만드는 `MX_SPI2_Init()`/`MX_SPI3_Init()`은 호출하지 않습니다.** `pi_spi.c`와 `imu_ism330.c`가 레지스터로 직접 설정합니다(USART2/3과 같은 방식).

## ★ 조립 후 반드시 할 것 (주행 전)

아래는 **로봇을 다 조립한 상태에서** 확정하는 값입니다. 코드에는 임시값이 들어 있습니다. 옵시디언 `실기 확인 목록`에도 같은 목록이 있습니다.

| # | 항목 | 코드 위치 | 현재 값 | 방법 |
|---|---|---|---|---|
| 1 | 조향 영점 | 서보 EEPROM | 미설정 | `OFF` → 네 바퀴를 자로 정면 정렬 → `ZERO ALL` → `ON` → `T 0 0 0 0` |
| 2 | 조향 방향(dir) | `joint.c` `joint_config[].dir` | 전부 +1 | `T 30`(서보1)부터 하나씩: 위에서 볼 때 반시계면 +1, 시계면 -1 |
| 3 | 조향 가동범위 | `joint.c` `min_deg/max_deg` **+ 시뮬 `sim/rl/config.py` `steer_lo_deg/steer_hi_deg`** | 전부 ±100° | `T`로 천천히 늘려 가며 구동모터·배선 간섭 각 확인. 바퀴마다 달라도 됨. 폭 180° 이상 유지. **두 곳을 같이 고친다** (시뮬은 모듈 순서 FL, FR, RL, RR) |
| 4 | 구동모터 ↔ 바퀴 | `main.c` `SWERVE_MODULE_MOTOR` | MOTOR1..4 = FL, FR, RL, RR | 바퀴 띄우고 `MTEST` → 어느 바퀴가 도는지 |
| 5 | 구동 방향 | `main.c` `MOTOR_DRIVE_SIGN` | 전부 +1 | `V 0.05 0 0`에서 뒤로 도는 바퀴의 모터 → -1 |
| 6 | 엔코더 방향 | `main.c` `ENCODER_SIGN` | 전부 +1 | 5번 후 `LOG`의 m/s가 음수인 모터 → -1 |

1~3은 **순서대로** 합니다. 영점 없이 범위를 넓히면 구동모터가 몸체에 부딪힐 수 있습니다. 4~6은 방향이 틀리면 로버가 엉뚱하게 가는 항목이라, 바퀴를 띄운 상태에서 먼저 확인합니다.

## 3. 브링업 순서

배선 후 처음 한 번 하는 작업입니다.

```
LOG                 화면 정리 (이후 완전 무음, 타이핑이 보임)
SCAN                버스에 뭐가 몇 번으로 잡혀 있나 확인
```

`SCAN` 결과가 비어 있으면 → 배선(PB10/GND), 서보 12V 전원, 보레이트를 확인하세요.

**ID 부여** (전부 ID=1로 나왔을 때. 서보 하나씩만 연결):

```
ID 254 4            연결된 서보 1개를 4번으로
                    → 분리하고 다음 서보 연결
ID 254 3
ID 254 2
ID 254 1
                    → 4개 전부 데이지체인 연결
SCAN                1·2·3·4 다 잡히는지 확인
```

높은 번호부터 부여하면 중간에 중복이 생겨도 덜 꼬입니다.

**영점 + 방향**:

```
OFF                 토크 풀기
                    → 자를 대고 바퀴 4개를 정면으로 정렬
ZERO ALL            지금 자세를 0도로 기록
ON                  토크 켜기
T 0 0 0 0           4개 다 정면 보면 성공
T 30 0 0 0          1번이 위에서 볼 때 반시계로 돌아야 정상
```

반대로 돌면 `Core/Src/joint.c`의 해당 서보 `dir`을 `-1`로 바꾸고 다시 빌드·플래시하세요. 4개 각각 확인해야 합니다. 좌우 대칭으로 장착했다면 한쪽은 `-1`이 되는 게 정상입니다.

**주행 확인**:

```
V 0.1 0 0           전진
V 0 0 0             정지
```

---

## 4. 자주 겪는 것

**포트는 한 번에 한 프로그램만 잡습니다.** `miniterm`이 `/dev/ttyACM0`을 열고 있으면 조이스틱 스크립트가 못 엽니다. 조이스틱 돌리기 전에 터미널을 닫으세요.

**USB는 STM32만 먹입니다.** 모터(12V)와 서보(12V)는 별도 전원입니다. USB만 꽂은 상태에서는 명령을 쳐도 프린트만 나오고 아무것도 움직이지 않습니다 — 정상입니다. 배선 검증 단계에서는 오히려 안전합니다.

**서보 VCC를 STM32에 연결하지 마세요.** 12V 외부 전원에만 직결하고, GND만 공통으로 묶습니다.

**`No debug probe detected`** → ST-Link가 USB에 안 잡힌 것입니다. `lsusb | grep 0483`으로 확인하세요. 안 보이면 케이블 문제일 가능성이 높습니다(충전 전용 케이블은 데이터선이 없어 아예 인식되지 않습니다).

**`PING`이 전부 FAIL** → 서보 전원·배선·ID를 확인하세요. 서보를 연결하지 않았다면 정상 결과입니다.

---

## 5. 아직 실측값이 아닌 것

다음 값들은 임시값이라 실제 측정 후 교체해야 합니다.

| 항목 | 위치 | 현재 값 |
|---|---|---|
| 모듈 장착 위치 | `main.c` `SWERVE_MODULES` | ±0.12 m (트랙·휠베이스 240mm 가정) |
| 최대 바퀴 속도 | `main.c` `SWERVE_MAX_WHEEL_MPS` | 0.3 m/s |
| 모듈↔구동모터 매핑 | `main.c` `SWERVE_MODULE_MOTOR` | 0→MOTOR1 … 3→MOTOR4 (실제 배선 미확인) |
| 모듈↔서보 매핑 | `main.c` `SWERVE_MODULE_SERVO` | FL→서보1, FR→서보3, RL→서보2, RR→서보4 (배치 확정) |
| 조향 원점·방향 | `joint.c` `joint_config[]` | offset=2048, dir=+1 (캘리브레이션 전) |
| 조향 가동범위 | `joint.c` `min_deg/max_deg` | 전부 ±100° (90° + 여유 10°, 바퀴별 간섭 확인 전) |

모듈 위치와 최대 속도가 틀려도 방향은 맞고 크기만 어긋납니다. 반면 **원점·방향·매핑이 틀리면 로버가 엉뚱한 방향으로 갑니다.**

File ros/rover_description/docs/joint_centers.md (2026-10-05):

# 조향축과 구동축 기준점

기준: base_link, X 전방 / Y 왼쪽 / Z 위. 로커 0, 조향 0 자세. 단위 mm.
조향축은 서보 출력축과 휠 허브의 연결 기준점입니다.
구동축 기준점은 조향축에서 수직 아래로 내린 점과 구동 회전축의 교점입니다.

| 모듈 | 조향축 XYZ (mm) | 조향축 바로 아래 구동축 XYZ (mm) | 실제 URDF wheel_joint 원점 XYZ (mm) |
|---|---|---|---|
| FL | (+102.431, +132.500, -45.313) | (+102.431, +132.500, -114.313) | (+102.431, +142.030, -114.313) |
| FR | (+102.431, -132.500, -45.313) | (+102.431, -132.500, -114.313) | (+102.431, -142.030, -114.313) |
| RL | (-102.431, +132.500, -45.313) | (-102.431, +132.500, -114.313) | (-102.431, +142.030, -114.313) |
| RR | (-102.431, -132.500, -45.313) | (-102.431, -132.500, -114.313) | (-102.431, -142.030, -114.313) |

조향축에서 구동축까지의 수직 거리는 69.000 mm입니다.
기존 wheel_joint 원점은 위 기준점에서 축 방향으로 바깥쪽 9.530 mm 이동한 점입니다.
두 점은 같은 회전축 위에 있습니다. 요청한 수직 아래 기준점을 표에 별도로 제공합니다.
좌표 정리에 따라 기존 URDF의 조립 형상·질량·관절 변환은 변경하지 않았습니다.

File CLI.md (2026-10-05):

# CLI

이 문서는 **ROS2 / Nav2 / 대회맵 주행** 명령만 담는다. 런치는 `ros/`, 조이스틱은 저장소 루트에서 실행한다.

| 다른 명령 | 문서 |
|---|---|
| 학습·증류·평가·재생 (`sim/rl`) | [sim/CLI.md](sim/CLI.md) |
| 펌웨어 빌드·플래시·터미널·세팅·조이스틱 직결·Pi SPI | [firmware/CLI.md](firmware/CLI.md) |

---

## 0. 네 가지 조합 — 어느 명령을 쓸지

**목표를 어떻게 주느냐**(RViz 클릭 / 텔레옵) × **차체명령을 누가 내느냐**(순수 IK / RL 잔차)
의 조합이다. 어느 경우든 그 아래 **펌웨어와 같은 공유 C 기구학**
(`swerve_ik_compute` → `swerve_fold_to_range`)을 지나 MuJoCo 액추에이터로 간다.

| | 목표 | 차체명령 | 명령 | 상태 |
|---|---|---|---|---|
| **1** | RViz 2D Goal Pose | Nav2 MPPI (순수 IK) | `mode:=nav2` (기본) | ✅ |
| **2** | RViz 2D Goal Pose | Nav2 MPPI **+ RL 잔차** | `mode:=nav2 rl:=true` | ✅ |
| **3** | 텔레옵 (조이스틱) | 사람 명령 (순수 IK) | `mode:=teleop` | ✅ |
| **4** | 텔레옵 (조이스틱) | 사람 명령 **+ RL 잔차** | — | ❌ **불가** |

```bash
cd ~/ksrc/ros
source /opt/ros/humble/setup.bash
python3 make_maps.py    # 맵이 없거나 지형 생성 코드를 바꿨을 때만

# 1. 클릭으로 목표 -> 순수 IK
ros2 launch nav2_ksrc.launch.py terrain:=sand

# 2. 클릭으로 목표 -> RL 잔차 (기본 모델 = 검증된 s13 @2.0M)
ros2 launch nav2_ksrc.launch.py terrain:=sand rl:=true

# 3. 텔레옵 -> 순수 IK   (두 번째 터미널에서 조이스틱, 아래)
ros2 launch nav2_ksrc.launch.py terrain:=sand mode:=teleop
```

**한 번에 하나의 런치만** 띄운다. 암석 대회맵은 전부 `terrain:=rock`.

### 4번(텔레옵 + RL)이 왜 불가인가

런치가 **거부한다** (`nav2_ksrc.launch.py`):

```python
if mode == "teleop" and use_rl:
    raise RuntimeError("teleop 모드에는 /plan 이 없으므로 rl:=true 를 쓸 수 없습니다")
```

정책 관측에 **기준경로가 들어간다** — lookahead 2점, 횡이탈 `e_y`,
`cos/sin(e_psi)`, 선행 목표점, 선행거리. 이 값들은 Nav2 `/plan` 에서 나온다
(`ros/policy_observation.py`). 텔레옵에는 경로가 없으므로 `e_y`·`e_psi` 가
**정의되지 않는다.** 0 을 채우면 정책이 학습 때 본 적 없는 분포 밖 입력을 받는다.

구조적인 이유다 — 이 정책은 "주행 보조" 가 아니라 **경로추종 보정**이고, 보정할
경로가 있어야 존재할 수 있다.

> 하고 싶다면: 텔레옵 명령 방향으로 **가상 직선 경로를 합성**해서 넣으면 된다
> (`e_y = 0`, `e_psi` = 기수와 명령방향 차, lookahead 는 그 직선 위). 학습 분포에
> 직선·`e_y≈0` 구간이 있으므로 완전히 밖은 아니다. 약 30행 작업이고 아직 안 했다.

> [!tip] 2번의 기본 모델 — `s13 @2.0M` (2026-10-04 검증)
> 런치 기본값이 `runs/s13_resid/ppo_1999900_steps.zip` 이다. holdout 100 에피소드
> 짝비교에서 **순수 IK 를 유의하게 이긴 유일한 체크포인트**다 (잡음 ON):
>
> | 지표 | 순수 IK | `s13 @2.0M` | |
> |---|---|---|---|
> | 횡오차 평균 | 21.68 mm | **19.80 mm** | **−8.7%** |
> | 횡오차 p90 | 46.58 mm | **42.34 mm** | **−9.1%** |
> | 기수오차 평균 | 7.38° | **7.12°** | **−3.5%** |
> | 완주율 | 95.0% | 95.0% | 유지 |
> | 슬립 평균 | **0.23** | 0.29 | +26% 악화 |
> | 소요시간 | **8.59 s** | 8.92 s | +3.8% 악화 |
> | 차체명령 포화 | **2.52%** | 11.68% | 4.6배 악화 |
>
> 다른 시드(`--seed0 2000`)와 다른 경로세트(`--path-seed 7777`)에서도
> **−10.0% / −8.6%** 로 재현된다. 시드 artifact 가 아니다.
>
> **단, 잡음 OFF 조건에서는 중립적이다** — 평균 횡오차 15.99 → 16.77mm (비유의),
> p90 46.26 → 42.75mm (−7.6%, 유의), 완주율 100 → 97%. 즉 **실기 측위가 예상보다
> 좋으면 이득이 줄어든다.** 측위 품질([[실기 확인 목록]] C1)이 이 정책의 값어치를
> 직접 정한다.
>
> `s9`·`s10`·`s11` 은 **목적 현상이 꺼진 과제**에서 학습·평가됐으므로 성능 판정이
> 아니었다. `s12`(잡음 ON, `w_resid` 0.06)·`s14`(`w_smooth` 0.06)·`s15`(`sigma_y` 0.05)
> 는 기각. 자세한 것은 [[RL 주행보조 진행상황]] 2026-10-04.

---

## 1. 대회맵 주행: RViz 목표 또는 텔레옵

실행 명령은 **0절의 표**에 있다. 이 절은 각 모드가 무엇을 띄우고 무엇을 확인하는지,
그리고 겪은 문제들을 설명한다.

**텔레옵 모드(3번)**는 런치를 켜 둔 채 두 번째 터미널에서 기존 마우스 조이스틱을
ROS 모드로 실행한다. 왼쪽 패드는 전후·게걸음, 오른쪽 패드 또는 Q/E는 회전,
스페이스바는 정지다. 패드에서 손을 떼거나 창 포커스를 잃으면 0 명령을 보낸다.
텔레옵에서 큰 방향 전환 중에는 차체가 거의 멈출 때까지 최대 0.5초 감속한다.
조향 목표가 한 주기에 60° 넘게 바뀌면 네 바퀴가 새 조향각의 10° 이내에
들어온 뒤 구동하는 규칙은 모든 모드의 `RoverEnv`에 공통 적용된다.

```bash
cd ~/ksrc
source /opt/ros/humble/setup.bash
export ROS_DOMAIN_ID=77 ROS_LOCALHOST_ONLY=1
python3 pi/teleop/teleop_joystick.py --ros --max-lin 0.25 --max-ang 0.8
```

텔레옵 런치는 MuJoCo 뷰어와 RViz의 대회맵·로버 위치를 함께 띄우며,
`map_server`만 활성화한다. Nav2 컨트롤러가 없어 `/cmd_vel` 발행자가 충돌하지
않는다. 이 모드에서 RViz의 2D Goal Pose는 주행 명령이 아니다. 조이스틱이
직접 `/cmd_vel`을 낸다. MuJoCo 창이 부담되면 `view:=false`를 런치에 추가해
RViz 맵만 볼 수 있다. 종료 후에도 명령이 끊기면 브리지의 0.5초 워치독이 정지한다.
규사맵의 최초 스폰과 `/reset_sim` 복귀 위치는 3° 이하 평탄 구역으로 제한하며,
경사 경계에서 로버 바퀴가 걸치지 않도록 풋프린트만큼 여유를 둔다. 같은 시드로
리셋하므로 복귀 위치는 매번 같다. 학습·평가 에피소드의 시작 위치 분포는 바꾸지 않았다.
텔레옵의 사전 감속만 끄려면 `teleop_guard:=false`, 조향각 구동 게이트만
끄려면 `drive_align_gate_deg:=0`을 런치에 추가한다. 이전 두 기능 모두 없던
동작과 비교하려면 둘 다 지정한다.
ROS 발행 옵션은 현재 `teleop_joystick.py`에 추가했다. `teleop_keyboard.py`와
`teleop_terminal.py`는 기존 Nucleo 직렬 프로토콜용이다.

```bash
source /opt/ros/humble/setup.bash
export ROS_DOMAIN_ID=77 ROS_LOCALHOST_ONLY=1
ros2 topic echo /cmd_vel --once          # 조이스틱을 움직인 상태에서 실행
ros2 topic echo /cmd_vel_applied --once  # 실제 IK 입력
ros2 topic echo /odom --once             # 맵 위 로버 위치
```

현재 저장소의 ROS 런치 파일은 `ros/nav2_ksrc.launch.py` 하나다. 기본 `nav2`
모드에서는 MuJoCo 브리지, `map_server`, `planner_server`, `controller_server`
(MPPI Omni), `behavior_server`, `bt_navigator`, `lifecycle_manager_navigation`,
RViz를 실행한다. `teleop` 모드에서는 브리지·맵 서버·RViz만 실행한다.
`amcl`과 `velocity_smoother`는 파라미터 파일에 항목이 있지만 현재 런치에서는 실행하지
않는다. 측위 대신 브리지가 `map → odom` 항등 변환과 참값 `odom → base_link`를 낸다.
Nav2 컨트롤러의 `/cmd_vel`은 브리지가 받아 공유 스워브 IK를 거쳐 **MuJoCo 조향·구동
액추에이터**에 적용한다. 브리지는 기본적으로 IK 전에 차체 명령을 0.10초 시정수로
저역통과하고 그 결과를 `/cmd_vel_filtered`에도 발행한다. 0 명령은 지연 없이 정지한다.
기본은 순수 IK(잔차 0)다. `rl:=true`로 띄우면 모델과 짝인 `vecnorm.pkl`을 로드하고
Nav2 `/plan` 기준 관측으로 3D 잔차를 계산한다. **`rl_model`/`rl_vecnorm` 을 반드시
명시한다** — 기본값이 `runs/s2/final.zip` 인데 `s2` 는 조향범위 ±180°, 옛 보상,
옛 `e_psi` 기준으로 학습해 지금 환경과 맞지 않는다 (0절 주의 참고).
`/rl_action`은 정규화 행동, `/rl_delta`는 요청된 차체속도 보정,
`/cmd_vel_applied`는 포화 처리 후 실제 IK 입력이다.
이 런치만으로 실제 STS/Cytron 모터에 명령이 나가지는 않는다.
STM32의 현재 `Swerve_Drive()`는 조향 명령과 구동 PWM을 바로 보내므로,
실기에서도 같은 정렬 대기를 쓰려면 서보 각 피드백·캘리브레이션을 확인한 뒤
펌웨어 구동 제어에 별도로 반영해야 한다.

```bash
cd ~/ksrc/ros
source /opt/ros/humble/setup.bash
ros2 launch nav2_ksrc.launch.py terrain:=sand rl:=true
# 다른 모델: rl_model:=... rl_vecnorm:=...
# 필요하면 잔차만 절반으로 줄여 확인: rl_scale:=0.5
# 주행 중 켜고 끄기: ros2 service call /set_rl std_srvs/srv/SetBool '{data: false}'
```

RViz의 **2D Goal Pose**로 목표를 준 뒤 아래 토픽을 보면 정책이 적용됐는지
확인할 수 있다. `topic echo`는 계속 실행되므로 관심 있는 토픽마다 별도 터미널을
쓴다. 목표에 도착해 `/cmd_vel`이 0이면 정책 잔차도 0이다.

```bash
source /opt/ros/humble/setup.bash
export ROS_DOMAIN_ID=77 ROS_LOCALHOST_ONLY=1
ros2 topic echo /plan --once             # Nav2 경로 수신
ros2 topic echo /rl_action                # [Delta vx, Delta vy, Delta omega] 정규화 행동
ros2 topic echo /rl_delta                 # 요청 보정: m/s, m/s, rad/s
ros2 topic echo /cmd_vel_filtered         # 보정 전 Nav2 명령
ros2 topic echo /cmd_vel_applied          # 보정 후 IK 입력
ros2 service call /set_rl std_srvs/srv/SetBool '{data: false}'
ros2 service call /set_rl std_srvs/srv/SetBool '{data: true}'
```

필터 명령과 최종 명령은 포화 처리 때문에 `/rl_delta`만큼 정확히 차이 나지 않을
수 있다. 정책은 pure pursuit 출력으로 학습됐으므로 Nav2 MPPI에서 성능 향상을
보장하는 실험은 아니다. 실제 주행 결과는 순수 IK와 같은 목표에서 비교한다.

### 왜 한 런치로 합쳤나

브리지와 Nav2를 각각 실행하던 구성에서는 브리지 누락, 서로 다른 지형·맵, 서로 다른
ROS 도메인 때문에 Nav2가 `/odom`·TF를 못 받거나 다른 실행의 노드와 섞일 수 있었다.
실패 당시 로그에는 `map_server` 활성화 실패, 오래된 `/odom` 타임스탬프, 현재 맵과
크기가 다른 맵이 함께 보였다. **다른 ROS 실행과의 충돌은 유력한 원인이지만 로그만으로
단정할 수는 없다.** 통합 런치는 같은 프로세스 묶음에서 지형에 맞는 맵을 고르고,
모든 자식에 `ROS_DOMAIN_ID=77`, `ROS_LOCALHOST_ONLY=1`을 설정해 이 문제를 피한다.
ROS 자체가 한 런치를 요구하는 것은 아니다. 아래처럼 분리 실행해도 같은 환경·맵·
라이프사이클 설정을 맞추면 된다. 기존 맵 파일 누락은 `make_maps.py`로 생성한다.

### 왜 2D Goal Pose 뒤에 조향이 튀었나

RViz의 **2D Goal Pose는 차체 속도나 바퀴각을 직접 보내지 않는다.** 클릭 위치가 목표
`x, y`, 드래그 방향이 최종 yaw이며, Nav2가 경로와 `/cmd_vel`을 계산한다. 이전 시뮬
조향 액추에이터는 큰 목표각을 즉시 받는 위치 제어(`kp=12`, `kv=0`)였다. 고정된
−90° 목표각 시험에서도 실제 바퀴가 약 −132°까지 지나치고 최대 35.6 rad/s로 움직였다.
따라서 MPPI 출력이 변하기 전에 조향 모델 자체가 과도하게 반응했다. 현재 코드는
`steer_kv=0.30` 감쇠를 넣고 목표각을 제어 주기마다 최대 `5.2 rad/s ÷ 50 Hz`만큼
진행시킨다. 같은 스텝 시험에서 초과각은 0.14°, 최대 속도는 약 4.7 rad/s였다.
빠르게 변하는 명령 시험에서는 최대 5.18 rad/s였다. 이는 시뮬 단위 시험 결과이며
RViz GUI에서 연속 주행한 결과를 뜻하지 않는다. 저장된 RL 정책의 성능도 변경된
조향 물리에서 다시 평가해야 한다.

RViz에서 **차체 위치가 순간이동하던 문제**도 따로 있었다. 전복 후 브리지가 자동으로
환경을 리셋해 스폰 위치를 다시 발행했기 때문이다. 지금은 전복 시 구동을 멈추고
현재 위치를 유지하며, `/reset_sim`을 호출할 때만 원래 스폰으로 리셋한다.

목표를 눌러도 움직이지 않는 현상은 별개로 확인한다. Nav2 노드가 `active`가 아니면
목표가 수행되지 않는다. 또 목표가 시작 위치에서 0.15 m 이내이고 방향 차이가 0.50 rad
이내면 현재 목표 허용오차 안이라 즉시 `Reached the goal!`이 된다. 실제 시험 중 한
목표는 시작 위치에서 약 0.04 m 떨어져 있었다. 먼저 충분히 떨어진 통과 가능 지점을
클릭하고 드래그한다. RViz의 **2D Pose Estimate**는 이 브리지의 스폰 위치를 바꾸지
않으며, `Publish Point`는 현재 웨이포인트 명령으로 연결되지 않았다.

### 통합 실행 (권장)

```bash
source /opt/ros/humble/setup.bash
cd ~/ksrc/ros
python3 make_maps.py                         # 맵이 없거나 지형/맵 생성 코드를 바꿨을 때
ros2 launch nav2_ksrc.launch.py terrain:=sand
```

`terrain:=rock`으로 암석 맵·지형을 선택한다. `rviz:=false`는 RViz만,
`view:=false`는 MuJoCo 창만 끈다. `cmd_filter_tau:=0`이면 이번 차체 명령 필터를
꺼서 기존 동작과 비교할 수 있다. 이 필터는 **브리지 안에만** 있으며 Nav2의
`velocity_smoother` 노드를 실행하는 것은 아니다. `domain_id:=78`처럼 도메인을 바꾸면 별도
터미널의 `ROS_DOMAIN_ID`도 같은 값으로 맞춘다. **통합 런치의 도메인 설정은 그
런치가 띄운 자식 프로세스에만 적용된다.** 세 번째 진단 터미널에는 자동으로
전파되지 않는다. 종료는 런치를 실행한 터미널에서
Ctrl-C를 누른다. 동일한 Nav2나 브리지를 중복 실행하지 않는다.

### 브리지와 Nav2 런치를 분리 실행

두 터미널 **각각** 먼저 다음 환경을 설정한다. 별도 `ros2` 진단 터미널도 같다.

```bash
source /opt/ros/humble/setup.bash
export ROS_DOMAIN_ID=77
export ROS_LOCALHOST_ONLY=1
cd ~/ksrc/ros
```

터미널 A: 브리지. `--view`를 빼면 MuJoCo 창 없이 실행된다. 기본 `--seed 0`,
`--d 0.5`, `--cmd-filter-tau 0.10`이며, 지형은 Nav2 런치와 같아야 한다.
필터 비교 시 `--cmd-filter-tau 0`을 준다. 정책 시험은 아래 둘째 명령처럼
모델과 vecnorm을 함께 지정한다.

```bash
python3 mujoco_bridge.py --terrain sand --view
python3 mujoco_bridge.py --terrain sand --view \
  --model ../sim/rl/runs/s2/final.zip --vecnorm ../sim/rl/runs/s2/vecnorm.pkl
```

터미널 B: 같은 지형의 Nav2와 RViz. 이미 브리지를 띄웠으므로 `bridge:=false`를 준다.
맵이 없다면 먼저 `python3 make_maps.py`를 실행한다.

```bash
ros2 launch nav2_ksrc.launch.py terrain:=sand bridge:=false
```

### 런치 없이 노드를 하나씩 실행

각 명령을 **서로 다른 터미널**에서 실행한다. 모든 터미널에 위의 `source`,
`ROS_DOMAIN_ID`, `ROS_LOCALHOST_ONLY`, `cd`를 반복한다. 맵 파일이 없다면 먼저
`python3 make_maps.py`를 실행한다. 실행 순서는 브리지 → Nav2 서버 5개 →
라이프사이클 매니저 → RViz다. `map_server`의 `yaml_filename`은 런치가 덮어쓰던
값이므로 수동 실행에서는 반드시 실제 맵 파일을 준다. 암석 지형이면 브리지의
`sand`와 맵 파일명의 `sand`를 함께 `rock`으로 바꾼다.

```bash
# 터미널 1: MuJoCo 브리지
python3 mujoco_bridge.py --terrain sand --view

# 터미널 2: 정적 맵 서버
ros2 run nav2_map_server map_server --ros-args \
  --params-file "$PWD/nav2_params.yaml" \
  -p yaml_filename:="$PWD/maps/arena_sand.yaml"

# 터미널 3: 전역 경로 계획
ros2 run nav2_planner planner_server --ros-args \
  --params-file "$PWD/nav2_params.yaml"

# 터미널 4: MPPI Omni 경로 추종 → /cmd_vel
ros2 run nav2_controller controller_server --ros-args \
  --params-file "$PWD/nav2_params.yaml"

# 터미널 5: 복구 행동
ros2 run nav2_behaviors behavior_server --ros-args \
  --params-file "$PWD/nav2_params.yaml"

# 터미널 6: 목표 행동 트리
ros2 run nav2_bt_navigator bt_navigator --ros-args \
  --params-file "$PWD/nav2_params.yaml"

# 터미널 7: 위 5개 Nav2 서버를 configure → activate
ros2 run nav2_lifecycle_manager lifecycle_manager --ros-args \
  -r __node:=lifecycle_manager_navigation \
  -p use_sim_time:=false -p autostart:=true \
  -p 'node_names:=[map_server,planner_server,controller_server,behavior_server,bt_navigator]'

# 터미널 8: RViz
ros2 run rviz2 rviz2 -d "$PWD/rviz/ksrc.rviz" --ros-args -p use_sim_time:=false
```

라이프사이클 매니저 없이 서버 실행 명령만 입력하면 Nav2 서버는 `unconfigured`에
머물러 주행할 수 없다. 현재 런치와 동일하게 `use_sim_time:=false`를 유지한다.

### 목표를 보내기 전 확인

통합 런치를 썼더라도 진단용 터미널에서 다음 환경을 다시 설정한다.
`domain_id:=`를 바꿨다면 `77` 대신 그 값을 쓴다.

```bash
source /opt/ros/humble/setup.bash
export ROS_DOMAIN_ID=77
export ROS_LOCALHOST_ONLY=1
ros2 node list --no-daemon
ros2 topic info /cmd_vel -v --no-daemon
```

`node list`가 비어 있으면 도메인이 다르거나 런치가 종료된 것이다. 노드는
보이는데 `/cmd_vel` 발행자가 없다면 `controller_server`가 실행·활성화됐는지
확인한다. 발행자가 있어도 목표 주행 중이 아니면 `topic echo`는 새 메시지가
올 때까지 기다린다. 다음 명령을 한 번에 하나씩 실행한다.
`topic hz`와 끝나지 않는 `topic echo`는 Ctrl-C로 종료한다. `map_server`와
`bt_navigator`가 `active`이고 `/odom`이 계속 갱신돼야 한다. RViz에서
**2D Goal Pose**를 눌러 목표점에서 클릭·드래그한다. 전복으로 구동이 잠겼을 때는
`/reset_sim`을 호출하면 처음 `--seed`의 스폰으로 돌아간다.

**클릭한 지점이 목적지이고, 드래그는 목적지에서의 최종 방향만 정한다.** 로버 위를
클릭한 뒤 멀리 드래그해도 목적지는 로버 근처다. 최근 로그에서도 현재 위치
`(1.36, 0.14)`에 대해 목표가 `(1.34, 0.14)`여서 15 cm 목표 허용오차 안이었다.
구동 확인은 로버에서 0.5 m 이상 떨어진 주행 가능 지점을 먼저 클릭한다.

```bash
ros2 lifecycle get /map_server
ros2 lifecycle get /bt_navigator
ros2 topic hz /odom
ros2 topic echo /goal_pose --once             # 실행한 다음 RViz에서 목표를 찍는다
ros2 topic echo /odom --once                  # 현재 로버 좌표와 비교
ros2 topic echo /cmd_vel --no-daemon         # Nav2 원본 명령. 목표를 찍기 전에 켠다
ros2 topic echo /cmd_vel_filtered --no-daemon  # RL 전 필터 명령
ros2 topic echo /cmd_vel_applied --no-daemon   # IK 에 들어간 최종 명령
ros2 topic echo /rl_action --no-daemon         # 정책 행동 (rl:=true 시)
ros2 service call /reset_sim std_srvs/srv/Trigger '{}'
```

---

## 2. 진단·비교용 런치 옵션 (2026-10-03 추가)

### `/plan` 꺾임각 분포 재기 — **지금 가장 급한 측정**

학습·평가 경로를 만드는 `sim/rl/path.py` `make_path` 가 막혔을 때 선회각 제한을
170° 까지 풀어서, 실측 꺾임각이 **p90 148~166°, 최대 168°** 다 (헤어핀 — 로버가
멈춰서 제자리 회전을 해야 통과한다). Nav2 planner 는 그런 경로를 내지 않는다.
그 차이가 순수 IK 기준선·`s9`·`s10` 판정 전부에 실려 있다.

```bash
# 터미널 1: Nav2 (1번과 동일)
cd ~/ksrc/ros && source /opt/ros/humble/setup.bash
ros2 launch nav2_ksrc.launch.py terrain:=sand

# 터미널 2: /plan 집계
cd ~/ksrc/ros && source /opt/ros/humble/setup.bash
export ROS_DOMAIN_ID=77 ROS_LOCALHOST_ONLY=1
python3 plan_stats.py
#  -> RViz 의 2D Goal Pose 로 목표를 10~20개 찍고 Ctrl-C
#  -> 누적 꺾임각 분포 + make_path 와의 비교가 출력된다
```

`--resample` 기본값 0.264 m 는 **pure pursuit 의 선행거리 L** 과 같다. Nav2 경로는
점 간격이 코스트맵 해상도(0.02 m 급)라 점마다 재면 양자화 잡음이 지배한다
(직각 90° 1회를 0.02 m 로 재면 평균 0.9°, 0.264 m 로 재면 15.0°).

### 조향 가동범위 바꿔 보기

```bash
ros2 launch nav2_ksrc.launch.py terrain:=sand mode:=teleop steer_limit_deg:=135
```

| 한계 | 이력 | 게이트 | 슬립 | `\|조향각\|>110°` (모터가 타이어 밖) |
|---|---|---|---|---|
| ±100° (기본) | 20° | 10.85% | 0.198 | **0.00%** |
| ±135° | 90° | **7.85%** | **0.175** | **3.25%** |

±135° 는 게이트·슬립을 개선하지만 주행 중 3.25% 의 시간에 **모터가 로버의 최외곽**이
된다 (최대 돌출 36.5 mm, 좌우 전폭 328→401 mm). 그 최외곽이 굴러가는 타이어가 아니라
고정 하우징이라 턱에 걸린다. 180° 반전 횟수는 **범위와 무관하게 360° 스윕 당 2회로
고정**이고 위치만 밀린다 (±100 → 100°/280°, ±135 → 136°/315°).

### 접기 선택을 "모터가 차체 안쪽" 으로 바꿔 보기

```bash
ros2 launch nav2_ksrc.launch.py terrain:=sand mode:=teleop mech_fold:=true
```

조향각 θ 와 θ±180° 는 바퀴 속도 부호를 뒤집으면 **차체 운동이 완전히 동일**하다.
구동모터가 바퀴 축과 동축이라 θ=±90° 에서 차체 전방/후방을 향하므로, **앞 모듈은
뒤로, 뒤 모듈은 앞으로** 접으면 네 모터가 가운데로 모인다:

| 횡걸음 조합 | 모터 외접반경 | 전후 치수 |
|---|---|---|
| `+90 +90 +90 +90` (기본 규칙이 내는 것) | 217.3 mm | 364.6 mm |
| `FL−90 FR+90 RL+90 RR−90` (`mech_fold:=true`) | **118.4 mm** | **2.6 mm** |

> [!warning] **채택안이 아니다.** 파이썬 시뮬 전용이고 공유 C 에 없다
> in-loop 짝비교(100 에피소드, 순수 IK): 완주율 **96.0 → 71.0%**, 고착 **3 → 28%**,
> 조향 대기 9.78 → 17.90%. 이력이 없어서 명령 급변 지점마다 분기를 추가 전환한다.
>
> 단 그 측정은 **헤어핀 경로 위에서 나온 것**이라 기각 증거가 아니다 — 현실적인
> 경로에서 재측정해야 한다. **텔레옵(매끄러운 입력)에서는 유효한 거래**다:
> 360° 스윕 당 반전 2 → 4회, 반전 1회가 약 0.6초, 그리고 게이트 트리거는
> `driving` 을 요구하므로 속도 0 으로 지나면 공짜다.
> 자세한 것은 [[조향 회전 제한 설계]].

### 게이트 끄고 비교

```bash
ros2 launch nav2_ksrc.launch.py terrain:=sand mode:=teleop drive_align_gate_deg:=0
ros2 launch nav2_ksrc.launch.py terrain:=sand mode:=teleop teleop_guard:=false
```

조합도 된다: `mech_fold:=true steer_limit_deg:=135 drive_align_gate_deg:=0`

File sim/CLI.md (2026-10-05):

# 시뮬 · 학습 CLI

0~5절의 학습·평가 명령은 `sim/rl/`에서 실행한다. 설명과 학습 결과는 [README.md](README.md),
ROS/Nav2 런치는 [루트 CLI.md](../CLI.md), 펌웨어는 [firmware/CLI.md](../firmware/CLI.md).

```bash
cd ~/ksrc/sim/rl
```

---

## 0. 빌드 / 검증

펌웨어 C 코드를 공유 라이브러리로 빌드한다. **기구학을 수정했으면 반드시 먼저 실행한다** —
시뮬과 STM32 가 같은 `firmware/common/*.c` 를 쓰기 때문에, 안 하면 정책이 학습한 기구학과
실기체 기구학이 어긋난다.

```bash
bash ../build.sh
```

모델 물리 검증 9종. 인자 없음.

```bash
python3 check_model.py
```

| | 검증 |
|---|---|
| [1] | 평지 정착 — 차체 높이, 로커각, 접촉력 합 = 무게 |
| [2] | 디퍼렌셜 — `rock_L + rock_R = 0` |
| [3] | 풀스로틀 — 차체속도가 이론 무부하와 일치 |
| [4] | 비틀림 접지 — 40mm 턱에서 네 바퀴 유지 |
| [5] | 횡경사 유지 — 슬립모델 ON, 횡방향 접지력 |
| [6] | 방향별 추종 — 전진/후진/게걸음/대각/제자리회전 |
| [7] | 요 외란 저항 |
| [8] | 조향 스텝 응답 |
| [9] | 누적 조향 드리프트 — 180° 등가 접기 검증 |

견인력 곡선과 고착 재현 검증. 인자 없음.

```bash
python3 test_terramech.py
```

---

## 1. 학습

조향 목표각이 한 주기에 60° 넘게 바뀌는 큰 방향 전환에서는 네 바퀴가 목표의
10° 이내에 들어올 때까지 구동을 함께 보류하는 규칙이 `RoverEnv`의 기본값이다.
학습·평가·RViz 순수 IK·RViz RL·텔레옵에 동일하게 적용된다. 평소 작은
조향 오차마다 멈추지 않도록 큰 전환에만 대기를 시작한다.
기존 `runs/s2`와 `runs/s3_path_reward`는 경로 시작 투영·로버 크기 이격을
고치기 전에 학습했다. `runs/s4_route_fix`는 수정 전 보상으로 학습했다.
현재 보상 함수의 성능 기준으로 간주하지 않는다.
새 정책은 별도 디렉터리에 학습하고 순수 IK와 짝비교한다.
보상 함수를 수정해 재학습할 때는 `reward.py`를 바꾸고 실행마다 다른
`--out` 디렉터리를 지정한다. 학습 시작 시 사용한 `reward.py`와 `env.py`가
그 디렉터리의 `src/`에 복사된다.

```bash
cd ~/ksrc/sim/rl
python3 train.py --steps 1000000 --envs 16 --terrain sand --stage1 --out runs/s5_reward
python3 compare_policy.py --model runs/s5_reward/ppo_400000_steps.zip \
  --vecnorm runs/s5_reward/ppo_vecnormalize_400000_steps.pkl --episodes 30
```

완료된 s8을 **추가 200만 스텝** 이어 학습할 때는 모델과 관측 정규화 통계를
함께 복원한다. 새 디렉터리를 지정해야 기존 s8 결과와 당시 코드가 보존된다.

```bash
python3 train.py --resume runs/s8_paper_heading --steps 2000000 --envs 16 \
  --terrain sand --stage1 --out runs/s8_resume_2m
```

중간 체크포인트에서도 재개할 수 있다. `--resume runs/<이름>/ppo_4800000_steps.zip`
처럼 지정하면 같은 스텝의 `ppo_vecnormalize_4800000_steps.pkl`을 자동으로 읽는다.
`--steps`는 기존 스텝을 포함한 최종값이 아니라 **추가 스텝 수**다. 기존
`reward.py`·`env.py`와 현재 코드가 다르면 기본적으로 중단한다. 보상이나 환경을
의도적으로 바꾸며 이어 학습할 때만 `--allow-source-change`를 붙인다.
Stage 1 이외에는 커리큘럼 진행 상태가 저장되지 않아 `--d0`로 재개 난이도를
직접 지정해야 한다. 학습은 PPO rollout 크기(`512 × --envs`) 단위로 끝나므로
요청한 추가 스텝을 조금 넘을 수 있다. 모델·옵티마이저·정규화 통계·누적 스텝은
복원하지만 실행 중이던 에피소드와 난수 상태는 재현하지 않는다.

학습 중 20만 스텝마다 모델과 그 시점의 `vecnormalize`가 함께 저장된다.
40만 스텝은 예시일 뿐이며 20만·40만·60만·80만·100만 스텝을 같은 미학습
경로에서 비교해 횡오차·완주율·잔차 포화가 가장 나은 체크포인트를 고른다.
이전 `s4_route_fix`는 40만→400만 스텝 동안 횡오차가 악화됐으므로 `final`을
자동으로 최선으로 간주하지 않는다.
잔차 벌점의 영향만 확인할 때는 `reward.py`의 `w_resid`만 바꾸고 같은
`--seed`, `--path-seed`, 스텝 수로 별도 실행한 뒤 두 런의 같은 스텝
체크포인트를 비교한다.

두 명령의 `--drive-align-gate-deg` 기본값은 대기 해제 오차 10°다. 이전 동작과 비교할 때만
둘 다 `--drive-align-gate-deg 0`으로 맞춘다.

### teacher (특권 관측)

특권정보 43차원(흙 8 / 로버 3 / 차체속도 3 / 슬립 4 / 침하 4 / 수직항력 4 / 배걸림 2 /
지형스캔 15)을 인코더로 `z(8)` 에 압축한다. 실기체에서는 못 쓰고, 증류의 교사로만 쓴다.

```bash
python3 train.py --teacher --steps 4000000 --envs 16 --out runs/teacher
```

### blind (대조군)

같은 관측 길이인데 특권정보가 없다. teacher-student 구조가 **실제로 값어치가 있는지**
가르는 기준선이다.

```bash
python3 train.py --steps 4000000 --envs 16 --out runs/blind
```

### 인자

| 인자 | 기본값 | 설명 |
|---|---|---|
| `--steps` | 4000000 | 병렬 환경 전체의 정책 스텝 합계. 16환경에서는 PPO 반복마다 512×16=8192스텝씩 진행 |
| `--envs` | CPU 코어 수 | 병렬 환경. 16 코어면 16 |
| `--d0` | 0.0 | 시작 난이도 |
| `--episode-s` | 20.0 | 에피소드 최대 길이 [초]. 기본 50 Hz에서 최대 1000 정책 스텝, 10000 물리 스텝 |
| `--seed` | 0 | |
| `--out` | `runs/ppo` | 저장 경로 |
| `--resume` | 없음 | 기존 run 또는 모델 체크포인트와 짝인 정규화 통계를 복원 |
| `--allow-source-change` | off | 저장 당시와 보상·환경 코드가 다른 경우 명시적으로 허용 |
| `--teacher` | off | 특권 관측 + 인코더 |

기존 `--clip-steer-deg`/`--clip-duty`는 3D 잔차에 적용되지 않는 무효 옵션이라 제거했다.
순수 IK는 `compare_policy.py`에서 잔차 `a=0`으로 평가한다.

### 산출물

```
runs/<이름>/
  final.zip            최종 정책
  vecnorm.pkl          관측 정규화 통계  ← 평가할 때 반드시 같이 준다
  ppo_*_steps.zip      200k 마다 체크포인트
  ppo_vecnormalize_*.pkl
  tb/                  텐서보드 로그
```

> `vecnorm.pkl` 없이 정책만 돌리면 스케일이 어긋난 입력을 받아 결과가 무의미하다.

---

## 2. 증류 (teacher → student)

student 는 고유수용감각 이력만으로 `ẑ` 를 맞히도록 배운다. 정책 머리는 **동결**이고
`AdaptationModule` 만 학습한다. 데이터는 student 가 직접 굴러다니며 모은다 (DAgger).

```bash
python3 distill.py --teacher runs/teacher/final --vecnorm runs/teacher/vecnorm.pkl
```

| 인자 | 기본값 | 설명 |
|---|---|---|
| `--out` | `runs/teacher/student.pt` | |
| `--iters` | 30 | DAgger 반복 |
| `--steps-per-iter` | 6000 | 반복당 수집 스텝 |
| `--epochs` | 4 | 반복당 회귀 에폭 |
| `--batch` | 512 | |
| `--lr` | 1e-3 | |
| `--w-act` | 0.0 | 행동 손실 가중치. 0 = RMA 설정, >0 = Lee 2020 설정 |
| `--difficulty` | 1.0 | |
| `--buffer` | 200000 | 집계 버퍼 |

---

## 3. 진단 — 증류를 시작해도 되는지

**성공률만 보면 안 된다.** PPO 가 인코더를 무시하고 고유수용감각만으로 풀어버리면
`z` 가 죽은 변수가 되고, 성공률은 멀쩡한데 증류할 내용이 없다.

```bash
python3 probe_teacher.py --model runs/teacher/final --vecnorm runs/teacher/vecnorm.pkl
```

| | 재는 것 | 판정 |
|---|---|---|
| [1] | `z` 의 에피소드 간 표준편차 | max < 0.02 면 인코더가 상수 → 여기서 멈춤 |
| [2] | `z → 흙 파라미터` 선형 R² | 진단용. 판정용 아님 |
| [3] | `z` 를 **다른 에피소드 것으로 바꿔치기** 했을 때 낙폭 | 주 판정 |

[3] 은 같은 씨드(= 같은 지형·흙)로 쌍대 비교하고, 목표 도달 수·이동거리 같은
연속 지표를 주로 본다. 이진 성공률은 24 에피소드에서 표준오차가 10%p 라 검정력이 낮다.
`z=0` 은 정책이 본 적 없는 분포 밖 입력이라 보조로만 쓴다.

`--episodes` (기본 24), `--difficulty` (기본 1.0) 로 조절한다.

---

## 4. 평가

**학습 지형이 아니라 실제 경기장 STL 에서 재는 게 핵심이다.**

```bash
# 실제 규사 경사지형 (주 평가 대상)
python3 eval.py --arena --terrain sand --episodes 30 \
                --model runs/teacher/final --vecnorm runs/teacher/vecnorm.pkl

# 기준선만 (모델 없이)
python3 eval.py --arena --terrain sand --episodes 30

# 절차생성 랜덤 지형
python3 eval.py --difficulty 1.0 --episodes 30

# s2 정책을 순수 IK와 같은 시드·미학습 경로에서 직접 짝비교
python3 compare_policy.py --model runs/s2/final --vecnorm runs/s2/vecnorm.pkl \
                          --episodes 100
```

| 인자 | 기본값 | 설명 |
|---|---|---|
| `--model` / `--vecnorm` | 없음 | 없으면 기준선만 |
| `--arena` | off | 실측 STL 로 평가 |
| `--terrain` | `sand` | `sand`(규사 경사지형, 주) / `rock`(암석 착륙지, 후순위) |
| `--episodes` | 20 | |
| `--difficulty` | 0.8 | `--arena` 에서는 **흙에만** 영향 (지형은 항상 실측 STL) |
| `--episode-s` | 20.0 | |

### 비교군

| 이름 | 무엇 |
|---|---|
| PP+IK | 잔차 0 |
| 일률감속 ×0.8 / ×0.6 | 기본 차체 명령의 속도를 낮춤 |
| 경사스케줄 | IMU 피치로 속도 상한 조정 |
| RL 3-D | 차체속도 `(Δvx, Δvy, Δω)` 잔차 |

`eval.py`는 성능·고착 원인·경로오차·잔차 사용량을 출력한다. 정책 대 순수 IK의
직접 판정은 `compare_policy.py`의 짝비교와 95% 신뢰구간을 사용한다.

---

## 5. 보기

### MuJoCo 뷰어

창이 떠야 하므로 그래픽 세션이 있는 터미널에서 실행한다.

```bash
cd ~/ksrc/sim/rl
python3 view.py
```

| 인자 | 기본값 | 설명 |
|---|---|---|
| `--terrain` | `sand` | `sand` / `rock` / `proc`(절차생성) |
| `--d` | 1.0 | 난이도 |
| `--model` / `--vecnorm` | 없음 | 없으면 순수 IK |
| `--watch-run` | 없음 | 학습 run의 최신 체크포인트와 정규화 통계를 에피소드마다 다시 읽음 (`--model`과 동시 사용 불가) |
| `--seed` | 0 | 바꾸면 다른 맵 |
| `--static` | off | 물리 끄고 지형만 (제일 가벼움) |
| `--realtime` | 1.0 | 재생 배속. 0.3 이면 슬립 관찰용 |

마우스: 좌드래그 회전 / 우드래그 이동 / 휠 줌. `p` 일시정지, `r` 새 경로,
`o` 정책 보정 ON/OFF.
에피소드가 끝나면 결과를 찍고 자동 리셋한다.

학습을 보면서 실행하려면 터미널 둘을 쓴다. 첫 20만 스텝 체크포인트 전에는
뷰어가 순수 IK를 보여주고, 이후 에피소드 경계에서 새 정책을 자동으로 적용한다.

```bash
# 터미널 1: 학습
cd ~/ksrc/sim/rl
python3 train.py --steps 5000000 --envs 16 --terrain sand --stage1 \
  --out runs/s9_watch

# 터미널 2: 별도 MuJoCo 환경에서 최신 정책 재생
cd ~/ksrc/sim/rl
python3 view.py --terrain sand --stage1 --d 0 --watch-run runs/s9_watch
```

화면은 학습 워커의 실제 내부 상태가 아니라 같은 경로 세트에서 최신 정책을
따로 실행한 것이다. `--path-seed 4321`을 터미널 2에 붙이면 학습 경로와 다른
미학습 경로를 볼 수 있다. 뷰어도 CPU를 사용하므로 학습 속도는 줄어들 수 있다.

### 텐서보드

```bash
cd ~/ksrc/sim/rl
tensorboard --logdir runs/teacher/tb
# http://localhost:6006
```

여러 실행을 한 번에 비교하려면 상위 폴더를 준다:

```bash
cd ~/ksrc/sim/rl
tensorboard --logdir runs
```

올라가는 스칼라:

| 그룹 | 내용 |
|---|---|
| `rollout/` | success, stuck, tip, oob, slip, sink, goals, dist, frac, f_belly, f_lifted, duty_sat, duty_use, steer_use |
| `stuck_cause/` | belly, lost_load, blocked, slip_stuck (멈춘 원인 비율) |
| `curriculum/` | difficulty, success_rate |
| `train/` | SB3 기본 (loss, entropy, explained_variance, approx_kl …) |

### 텐서보드 없이 돌린 학습

stdout 로그를 사후에 그림으로 만든다.

```bash
python3 plotlog.py train.log -o trainlog.png
```

### 모델 2D 단면

```bash
python3 draw.py
```

---

## 전형적인 흐름

```bash
bash ../build.sh                                    # 기구학 C 빌드
python3 check_model.py                              # 물리 9종 통과 확인

python3 train.py --teacher --envs 16 --out runs/teacher      # ~50분
python3 probe_teacher.py --model runs/teacher/final \
        --vecnorm runs/teacher/vecnorm.pkl          # z 를 쓰는가? 아니면 여기서 멈춤

python3 distill.py --teacher runs/teacher/final \
        --vecnorm runs/teacher/vecnorm.pkl          # student 증류
python3 train.py --envs 16 --out runs/blind                  # 대조군 ~50분

python3 eval.py --arena --terrain sand --episodes 30 \
        --model runs/teacher/final --vecnorm runs/teacher/vecnorm.pkl
```

---

## 주의

- **`pkill -f` 로 학습을 죽이지 말 것.** 패턴이 자기 셸까지 잡아 세션이 같이 죽는다
  (이 프로젝트에서 네 번 발생). 실행할 때 PID 를 받아두고 그 PID 로 `kill` 한다.
- `--envs` 는 물리 코어 수를 넘기지 않는다. 16 코어에서 16 이 최대다.
- 학습 중에는 CPU 가 포화되므로 뷰어·평가를 같이 돌리면 둘 다 느려진다.
- 기하(`config.py`)를 바꾸면 이전 정책은 못 쓴다. teacher 부터 다시 돌려야 한다.

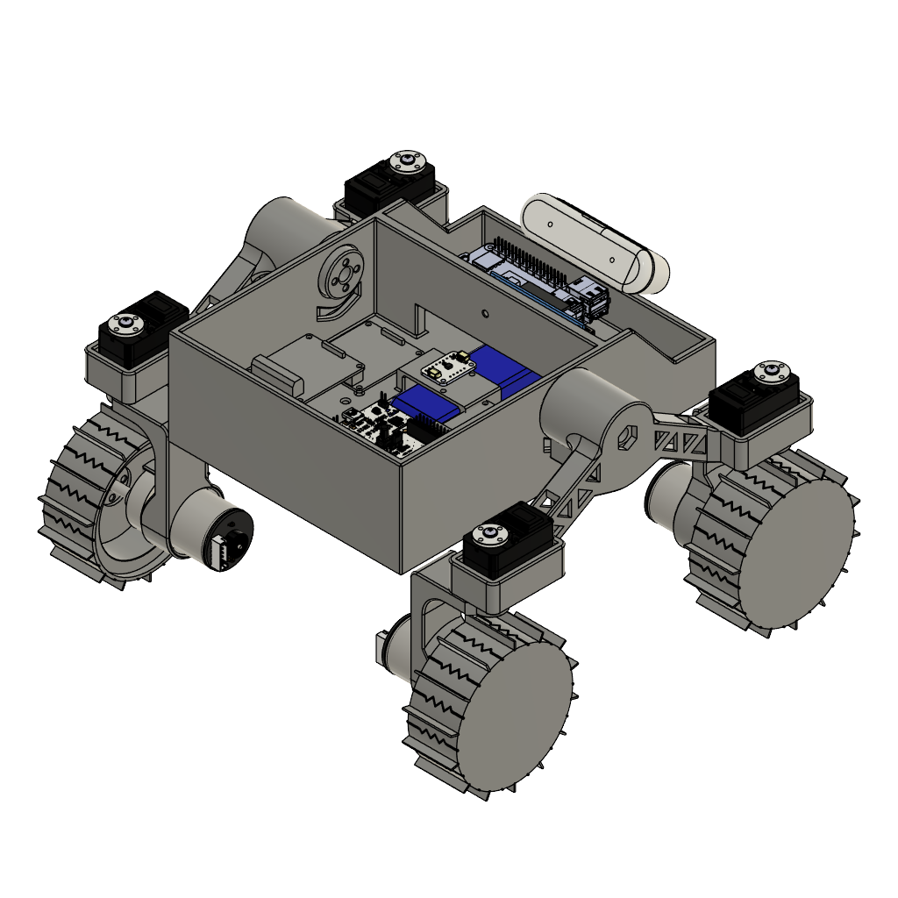
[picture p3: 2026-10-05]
ros/rover_description/docs/source_cad_preview.png

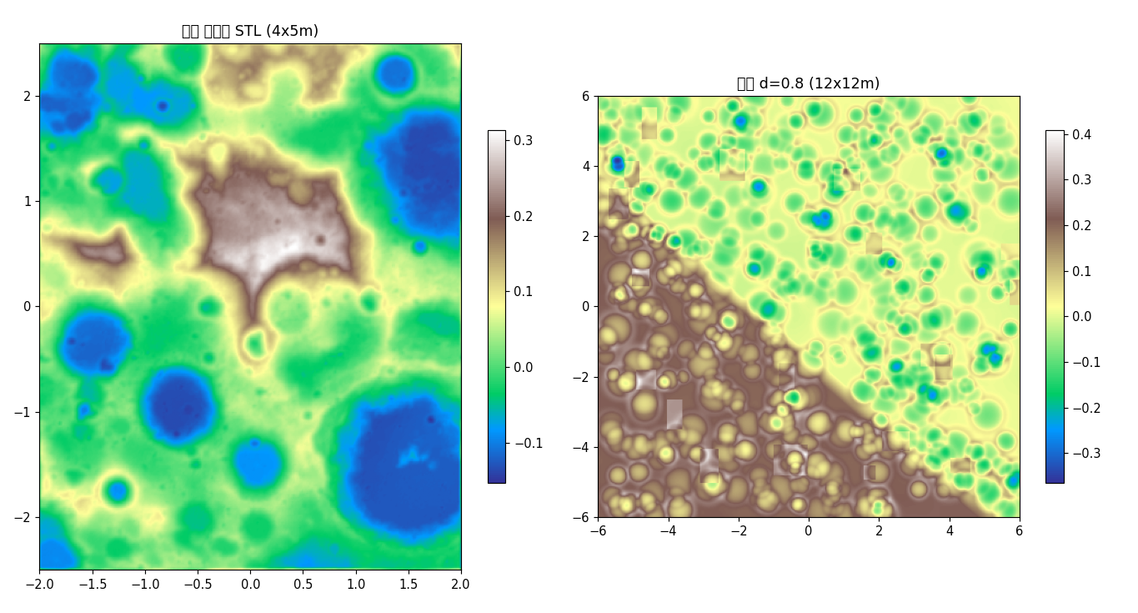
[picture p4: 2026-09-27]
sim/rl/terrain_compare.png

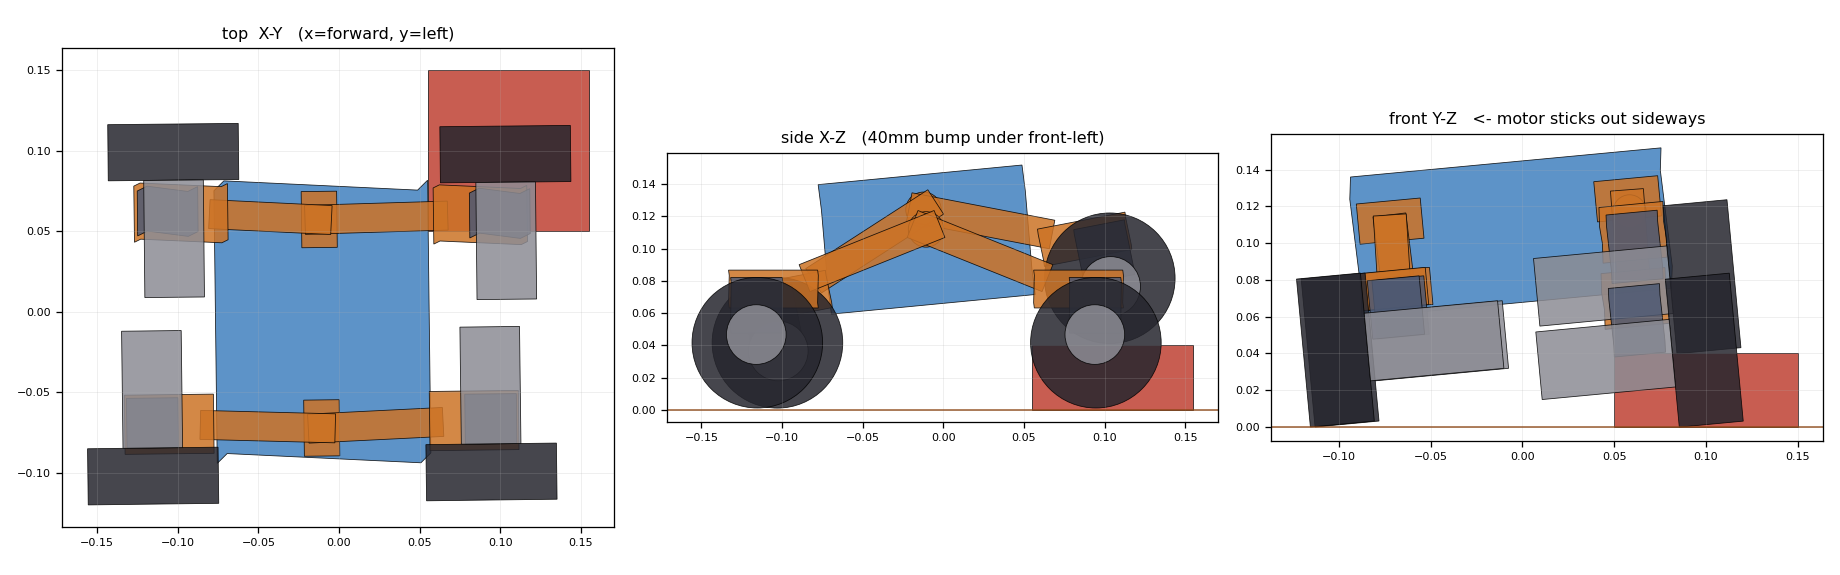
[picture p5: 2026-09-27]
sim/rl/rover_model.png

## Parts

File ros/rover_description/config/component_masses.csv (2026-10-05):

source_model | occurrence_id | link | mass_g | com_x_m | com_y_m | com_z_m
base_link | 203 | base_link | 408.5 | -0.00799901936328196 | -0.00021315532094278111 | -0.033880282420697176
Zippy2800 | 5132 | base_link | 178.1 | 0.025957055049194946 | -0.0010201551164827649 | -0.048797951884584384
MDD3A_cytron | 5293 | base_link | 20.0 | -0.01576380569525848 | 0.05416999764229548 | -0.034845034951755394
MDD3A_cytron | 5516 | base_link | 20.0 | -0.05894380344320256 | 0.05416999764229565 | -0.021345032427940426
RASPBERRY_PI_5 | 5661 | base_link | 71.2 | 0.07379093515778112 | 0.014267669196898045 | -0.02491992236183216
NUCLEO-F411RE | 6038 | base_link | 34.4 | -0.02685999777168036 | -0.03749999892897904 | -0.02999999932944775
MDD3A_cytron | 6734 | base_link | 12.9 | -0.029623803576179702 | -0.04471000241604556 | -0.028345040662874278
JACOBSPARTS-XL4015 | 5010 | base_link | 31.2 | 0.04161899928487216 | -0.027388201205203203 | -0.001801107071446165
omitted_large_gear |  | base_link | 15.6 | 0 | 0 | 0
arm_l_rev4 | 211 | left_rocker_link | 60.8 | -6.018240259360857e-06 | 0.030326396458958297 | -0.015317678659366661
STS3215_c | 1501 | left_rocker_link | 59.8 | -0.09013758039597196 | 0.04750063337386025 | -0.02668043828603173
STS3215_c | 1783 | left_rocker_link | 59.8 | 0.09013758044606841 | 0.04749936691946273 | -0.026680438255020606
omitted_small_gear |  | left_rocker_link | 5.8 | 0 | 0 | 0
arm_r_rev4 | 338 | right_rocker_link | 60.8 | 5.9510054844541675e-06 | -0.03037417369404501 | -0.015144049234616506
STS3215_c | 465 | right_rocker_link | 59.8 | -0.09013758044479377 | -0.04749936690708881 | -0.026680438256862383
STS3215_c | 674 | right_rocker_link | 59.8 | 0.09013758037842447 | -0.04750063336518733 | -0.02668043829782076
omitted_small_gear |  | right_rocker_link | 5.8 | 0 | 0 | 0
wheel_hub | 2394 | fl_steering_link | 21.6 | -0.002541879273811773 | -0.029568576591091376 | -0.03240431765827834
vb-motor-37 | 3608 | fl_steering_link | 203.2 | -0.007142630846711333 | -0.039408680177402775 | -0.0690000865392411
rover_wheel_rev4 | 4301 | fl_wheel_link | 47.1 | 1.3534365063182682e-08 | 1.1917175736975658e-08 | -0.0045908978838137115
wheel_hub_mirror | 2946 | fr_steering_link | 21.6 | -0.0025418655321750453 | 0.02956860096096613 | -0.0324042501175504
vb-motor-37 | 3596 | fr_steering_link | 203.2 | -0.007142630809325673 | 0.039408679896723295 | -0.06899992310214541
rover_wheel_rev4 | 4165 | fr_wheel_link | 47.1 | -1.3534365063182682e-08 | 1.1917175736975658e-08 | 0.0045908978838137115
wheel_hub_mirror | 2812 | rl_steering_link | 21.6 | 0.0025418655321750453 | -0.02956860096096613 | -0.0324042501175504
vb-motor-37 | 3247 | rl_steering_link | 203.2 | 0.0071426308093256695 | -0.039408679896723295 | -0.06899992310214537
rover_wheel_rev4 | 4309 | rl_wheel_link | 47.1 | 1.3534365063182682e-08 | 1.1917175736975658e-08 | -0.0045908978838137115
wheel_hub | 2063 | rr_steering_link | 21.6 | 0.002541879273811773 | 0.029568576591091376 | -0.03240431765827834
vb-motor-37 | 3080 | rr_steering_link | 203.2 | 0.007142630846711333 | 0.03940868017740277 | -0.06900008653924108
rover_wheel_rev4 | 3929 | rr_wheel_link | 47.1 | -1.3534365063182682e-08 | 1.1917175736975658e-08 | 0.0045908978838137115
D435_standalone_STL | sensor_d435 | camera_link | 72.0 | -0.01286942497011691 | 0.007499938459487053 | -0.0001114329962294606
IMU_standalone_STL | sensor_imu | imu_link | 2.4 | -0.006458225547000631 | 0.010199938328182657 | 0.0011149498809886382

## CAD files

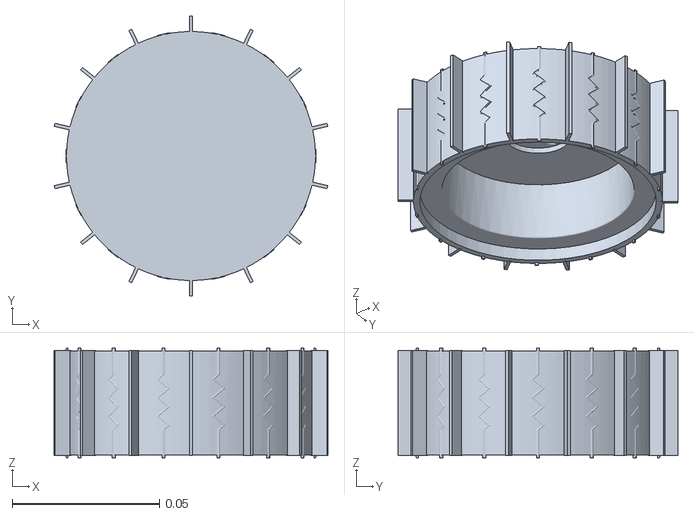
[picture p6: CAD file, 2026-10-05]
ros/rover_description/meshes/fl_wheel_link.stl
0.0929 x 0.095 x 0.0372

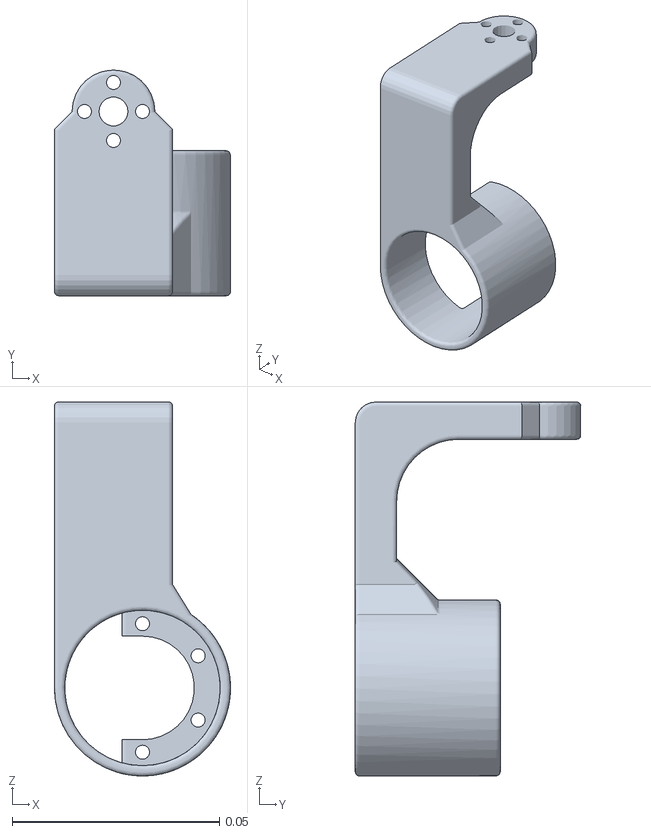
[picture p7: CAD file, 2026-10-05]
ros/rover_description/meshes/inertial_parts/component_2812.stl
0.0425 x 0.0544 x 0.0902

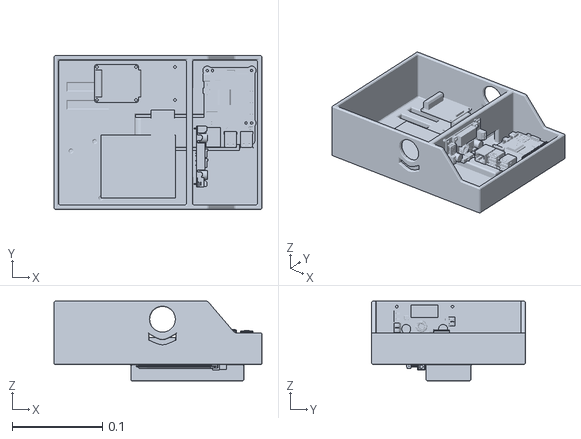
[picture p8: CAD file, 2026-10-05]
ros/rover_description/meshes/base_link.stl
0.23 x 0.17 x 0.088

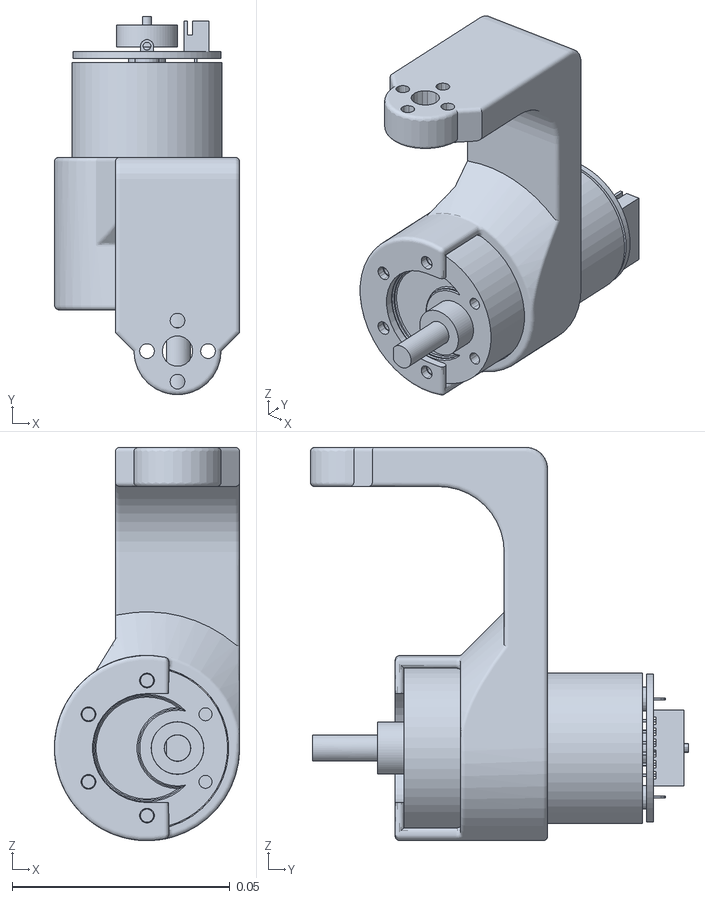
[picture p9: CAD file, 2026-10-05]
ros/rover_description/meshes/fr_steering_link.stl
0.0425 x 0.0867 x 0.0902

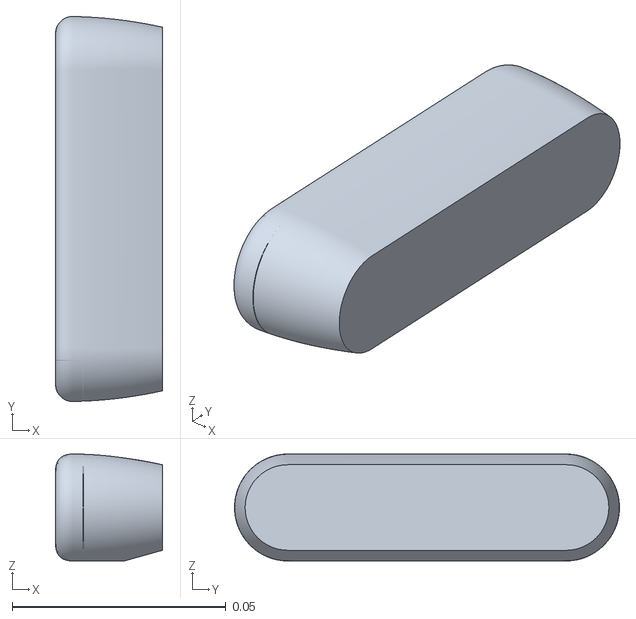
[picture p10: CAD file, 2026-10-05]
ros/rover_description/meshes/inertial_parts/component_sensor_d435.stl
0.025 x 0.09 x 0.025

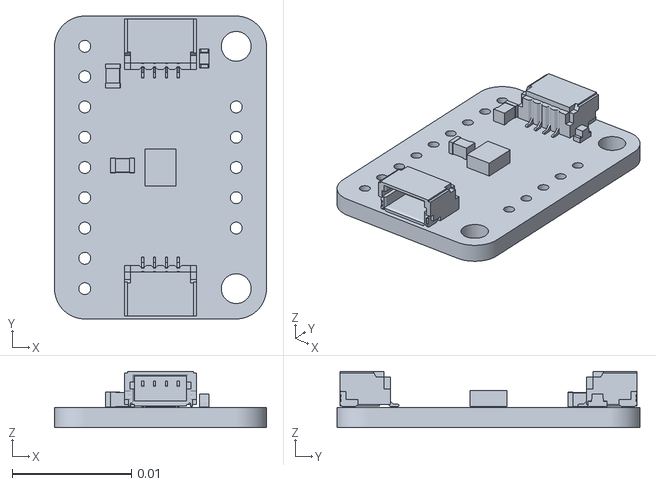
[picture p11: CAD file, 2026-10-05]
ros/rover_description/meshes/imu_link.stl
0.0178 x 0.0254 x 0.00473

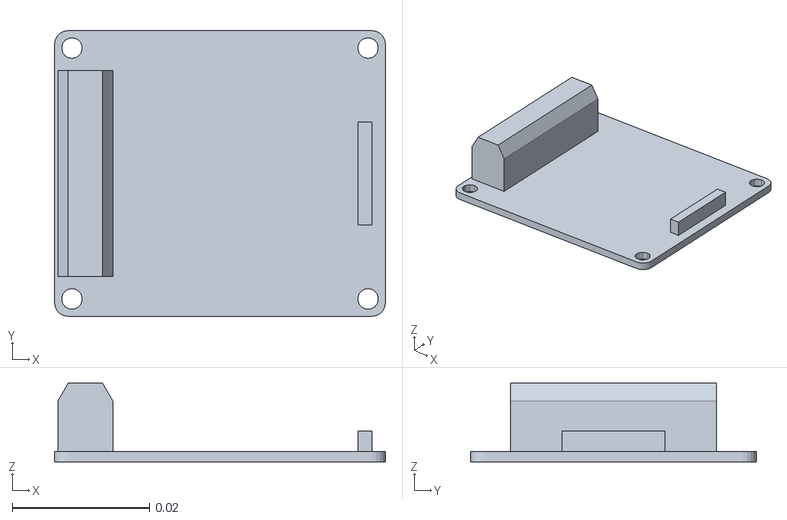
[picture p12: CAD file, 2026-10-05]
ros/rover_description/meshes/inertial_parts/component_5293.stl
0.0483 x 0.0417 x 0.0115

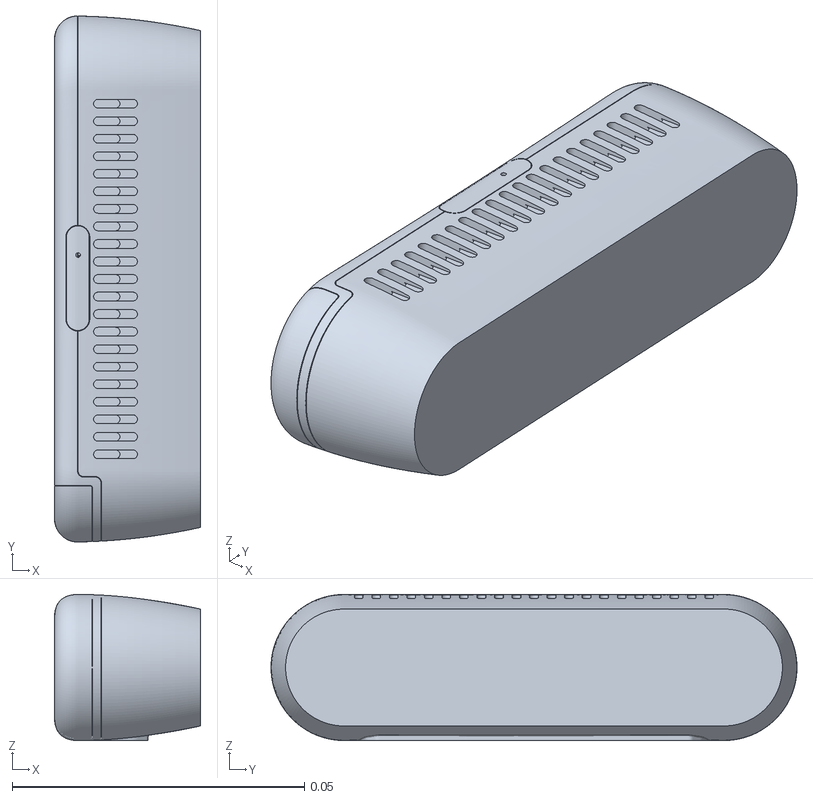
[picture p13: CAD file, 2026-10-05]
ros/rover_description/meshes/camera_link.stl
0.025 x 0.09 x 0.025

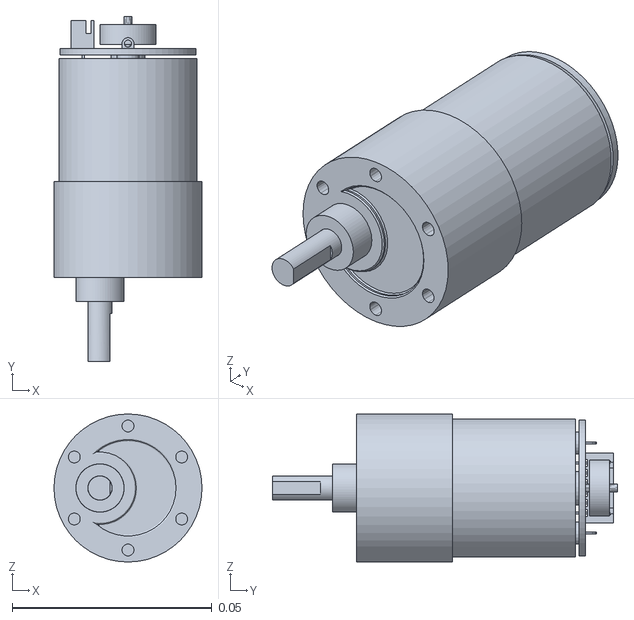
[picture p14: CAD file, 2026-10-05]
ros/rover_description/meshes/inertial_parts/component_3080.stl
0.037 x 0.0863 x 0.037

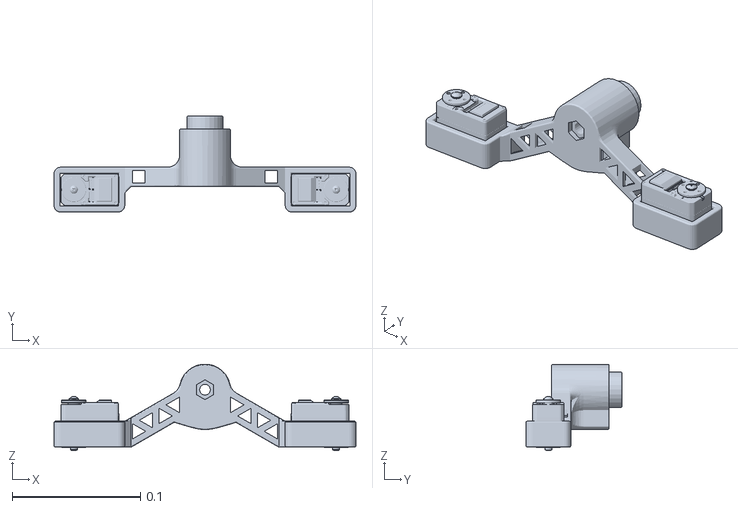
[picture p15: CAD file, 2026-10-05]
ros/rover_description/meshes/right_rocker_link.stl
0.236 x 0.075 x 0.0675

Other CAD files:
ros/rover_description/meshes/inertial_parts/component_3929.stl
ros/rover_description/meshes/inertial_parts/component_2946.stl
ros/rover_description/meshes/rr_steering_link.stl
ros/rover_description/meshes/inertial_parts/component_4309.stl
ros/rover_description/meshes/rl_steering_link.stl
ros/rover_description/meshes/inertial_parts/component_4301.stl
ros/rover_description/meshes/inertial_parts/component_5516.stl
ros/rover_description/meshes/rr_wheel_link.stl
ros/rover_description/meshes/base_link_sim.stl
ros/rover_description/meshes/fl_steering_link.stl
ros/rover_description/meshes/fr_wheel_link.stl
ros/rover_description/meshes/inertial_parts/component_1501.stl
ros/rover_description/meshes/inertial_parts/component_1783.stl
ros/rover_description/meshes/inertial_parts/component_203.stl
ros/rover_description/meshes/inertial_parts/component_2063.stl
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

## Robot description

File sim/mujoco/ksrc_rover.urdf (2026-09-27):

<?xml version="1.0"?>
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
<robot name="ksrc_rover">
  <link name="world"/>

  <link name="base_link">
    <inertial>
      <mass value="1.5"/>
      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
    </inertial>
    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
  </link>

  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
  <link name="front_marker_link">
    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
  </link>
  <joint name="front_marker_fixed_joint" type="fixed">
    <parent link="base_link"/>
    <child link="front_marker_link"/>
    <origin xyz="0.10 0 0.0375" rpy="0 0 0"/>
  </joint>

  <joint name="base_free_joint" type="floating">
    <parent link="world"/>
    <child link="base_link"/>
    <origin xyz="0 0 0.15" rpy="0 0 0"/>
  </joint>

  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
  <link name="fl_steer_link">
    <inertial><mass value="0.05"/>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</inertial>
    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
  </link>
  <joint name="fl_steer_joint" type="continuous">
    <parent link="base_link"/>
    <child link="fl_steer_link"/>
    <origin xyz="0.12 0.12 -0.04" rpy="0 0 0"/>
    <axis xyz="0 0 1"/>
  </joint>

  <link name="fl_wheel_link">
    <inertial><mass value="0.1"/>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</inertial>
    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
  </link>
  <joint name="fl_wheel_joint" type="continuous">
    <parent link="fl_steer_link"/>
    <child link="fl_wheel_link"/>
    <origin xyz="0 0 -0.0525" rpy="0 0 0"/>
    <axis xyz="0 1 0"/>
  </joint>

  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
  <link name="fr_steer_link">
    <inertial><mass value="0.05"/>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</inertial>
    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
  </link>
  <joint name="fr_steer_joint" type="continuous">
    <parent link="base_link"/>
    <child link="fr_steer_link"/>
    <origin xyz="0.12 -0.12 -0.04" rpy="0 0 0"/>
    <axis xyz="0 0 1"/>
  </joint>

  <link name="fr_wheel_link">
    <inertial><mass value="0.1"/>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</inertial>
    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
  </link>
  <joint name="fr_wheel_joint" type="continuous">
    <parent link="fr_steer_link"/>
    <child link="fr_wheel_link"/>
    <origin xyz="0 0 -0.0525" rpy="0 0 0"/>
    <axis xyz="0 1 0"/>
  </joint>

  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
  <link name="rl_steer_link">
    <inertial><mass value="0.05"/>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</inertial>
    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
  </link>
  <joint name="rl_steer_joint" type="continuous">
    <parent link="base_link"/>
    <child link="rl_steer_link"/>
    <origin xyz="-0.12 0.12 -0.04" rpy="0 0 0"/>
    <axis xyz="0 0 1"/>
  </joint>

  <link name="rl_wheel_link">
    <inertial><mass value="0.1"/>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</inertial>
    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
  </link>
  <joint name="rl_wheel_joint" type="continuous">
    <parent link="rl_steer_link"/>
    <child link="rl_wheel_link"/>
    <origin xyz="0 0 -0.0525" rpy="0 0 0"/>
    <axis xyz="0 1 0"/>
  </joint>

  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
  <link name="rr_steer_link">
    <inertial><mass value="0.05"/>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</inertial>
    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
  </link>
  <joint name="rr_steer_joint" type="continuous">
    <parent link="base_link"/>
    <child link="rr_steer_link"/>
    <origin xyz="-0.12 -0.12 -0.04" rpy="0 0 0"/>
    <axis xyz="0 0 1"/>
  </joint>

  <link name="rr_wheel_link">
    <inertial><mass value="0.1"/>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</inertial>
    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
  </link>
  <joint name="rr_wheel_joint" type="continuous">
    <parent link="rr_steer_link"/>
    <child link="rr_wheel_link"/>
    <origin xyz="0 0 -0.0525" rpy="0 0 0"/>
    <axis xyz="0 1 0"/>
  </joint>

  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
  <link name="ground_link">
    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
  </link>
  <joint name="ground_fixed_joint" type="fixed">
    <parent link="world"/>
    <child link="ground_link"/>
    <origin xyz="0 0 -0.01" rpy="0 0 0"/>
  </joint>
</robot>

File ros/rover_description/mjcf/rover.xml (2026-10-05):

<?xml version='1.0' encoding='utf-8'?>
<mujoco model="rover_measured">
  <compiler angle="radian" meshdir="../meshes" autolimits="true" inertiafromgeom="false" />
  <option timestep="0.002" gravity="0 0 -9.81" integrator="implicitfast" solver="Newton" iterations="100" />
  <visual />
  <default>
    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
  </default>
  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
  <worldbody>
    <light pos="0 -1 2" dir="0 0 -1" />
    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
    <body name="base_link" pos="0 0 0.161813">
      <freejoint name="floating_base" />
      <body name="left_rocker_link" pos="-5.22457895888e-19 0.085 0" quat="1 0 0 0">
        <joint name="left_rocker_joint" type="hinge" axis="0 1 0" damping="0.01" range="-0.523598775598 0.523598775598" />
        <body name="fl_steering_link" pos="0.10243139267 0.0475 -0.045313243866" quat="1 0 0 0">
          <joint name="fl_steering_joint" type="hinge" axis="0 0 1" damping="0.01" range="-1.57079632679 1.57079632679" />
          <body name="fl_wheel_link" pos="0 0.00953000068665 -0.0689999961853" quat="0.707106781187 -0.707106781187 0 0">
            <joint name="fl_wheel_joint" type="hinge" axis="0 0 1" damping="0.001" />
            <inertial mass="0.0471" pos="1.35343650632e-08 1.1917175737e-08 -0.00459089788381" fullinertia="3.19944436105e-05 3.19944370398e-05 5.54521855023e-05 2.35869009595e-12 1.15589879793e-11 3.18645968056e-12" />
            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
          </body>
          <inertial mass="0.2248" pos="-0.00670056574896 -0.0384631897972 -0.0654837671094" fullinertia="0.0001226757368 7.72455197191e-05 8.33426742573e-05 1.57566077196e-08 -5.3372430729e-06 -8.33157421512e-06" />
          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
        </body>
        <body name="rl_steering_link" pos="-0.10243139267 0.0475 -0.045313243866" quat="1 0 0 0">
          <joint name="rl_steering_joint" type="hinge" axis="0 0 1" damping="0.01" range="-1.57079632679 1.57079632679" />
          <body name="rl_wheel_link" pos="0 0.00953000068665 -0.0689999961853" quat="0.707106781187 -0.707106781187 0 0">
            <joint name="rl_wheel_joint" type="hinge" axis="0 0 1" damping="0.001" />
            <inertial mass="0.0471" pos="1.35343650632e-08 1.1917175737e-08 -0.00459089788381" fullinertia="3.19944436105e-05 3.19944370398e-05 5.54521855023e-05 2.35869009595e-12 1.15589879793e-11 3.18645968056e-12" />
            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
          </body>
          <inertial mass="0.2248" pos="0.0067005643948 -0.0384631918851 -0.0654836128865" fullinertia="0.000122675635391 7.72454316174e-05 8.3342682896e-05 -1.57549243504e-08 5.33696637792e-06 -8.33056406036e-06" />
          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
        </body>
        <inertial mass="0.1862" pos="-1.96512358754e-06 0.0404127009788 -0.0221390723934" fullinertia="8.66666054512e-05 0.00119831015184 0.00120679506749 3.27131653456e-09 -1.60179812582e-09 2.48078972061e-05" />
        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
      </body>
      <body name="right_rocker_link" pos="-5.22457895888e-19 -0.085 0" quat="1 0 0 0">
        <joint name="right_rocker_joint" type="hinge" axis="0 1 0" damping="0.01" range="-0.523598775598 0.523598775598" />
        <body name="fr_steering_link" pos="0.10243139267 -0.0475 -0.045313243866" quat="1 0 0 0">
          <joint name="fr_steering_joint" type="hinge" axis="0 0 1" damping="0.01" range="-1.57079632679 1.57079632679" />
          <body name="fr_wheel_link" pos="0 -0.00953000068665 -0.0689999961853" quat="0.707106781187 -0.707106781187 0 0">
            <joint name="fr_wheel_joint" type="hinge" axis="0 0 1" damping="0.001" />
            <inertial mass="0.0471" pos="-1.35343650632e-08 1.1917175737e-08 0.00459089788381" fullinertia="3.19944436105e-05 3.19944370398e-05 5.54521855023e-05 -2.35869009595e-12 1.15589879793e-11 -3.18645968056e-12" />
            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
          </body>
          <inertial mass="0.2248" pos="-0.0067005643948 0.0384631918851 -0.0654836128865" fullinertia="0.000122675635391 7.72454316174e-05 8.3342682896e-05 -1.57549243504e-08 -5.33696637792e-06 8.33056406036e-06" />
          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
        </body>
        <body name="rr_steering_link" pos="-0.10243139267 -0.0475 -0.045313243866" quat="1 0 0 0">
          <joint name="rr_steering_joint" type="hinge" axis="0 0 1" damping="0.01" range="-1.57079632679 1.57079632679" />
          <body name="rr_wheel_link" pos="0 -0.00953000068665 -0.0689999961853" quat="0.707106781187 -0.707106781187 0 0">
            <joint name="rr_wheel_joint" type="hinge" axis="0 0 1" damping="0.001" />
            <inertial mass="0.0471" pos="-1.35343650632e-08 1.1917175737e-08 0.00459089788381" fullinertia="3.19944436105e-05 3.19944370398e-05 5.54521855023e-05 -2.35869009595e-12 1.15589879793e-11 -3.18645968056e-12" />
            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
          </body>
          <inertial mass="0.2248" pos="0.00670056574896 0.0384631897972 -0.0654837671094" fullinertia="0.0001226757368 7.72455197191e-05 8.33426742573e-05 1.57566077196e-08 5.33724307291e-06 8.33157421512e-06" />
          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
        </body>
        <inertial mass="0.1862" pos="1.94316414914e-06 -0.0404283017018 -0.0220823770754" fullinertia="8.65008989919e-05 0.00119654837992 0.00120468351593 3.29521144284e-09 1.6044542867e-09 -2.47197004467e-05" />
        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
      </body>
      <body name="camera_link" pos="0.116619 0 -0.004122" quat="0.953716950748 0 0.300705799504 0">
        <body name="camera_depth_frame" pos="-0.0043 0.025 0" quat="1 0 0 0">
          <body name="camera_depth_optical_frame" pos="0 0 0" quat="0.5 -0.5 0.5 -0.5" />
        </body>
        <body name="camera_infra1_frame" pos="-0.0043 0.025 0" quat="1 0 0 0">
          <body name="camera_infra1_optical_frame" pos="0 0 0" quat="0.5 -0.5 0.5 -0.5">
            <camera name="camera_infra1" pos="0 0 0" quat="0 1 0 0" fovy="58" />
          </body>
        </body>
        <body name="camera_infra2_frame" pos="-0.0043 -0.025 0" quat="1 0 0 0">
          <body name="camera_infra2_optical_frame" pos="0 0 0" quat="0.5 -0.5 0.5 -0.5">
            <camera name="camera_infra2" pos="0 0 0" quat="0 1 0 0" fovy="58" />
          </body>
        </body>
        <body name="camera_stereo_center_frame" pos="-0.0043 0 0" quat="1 0 0 0">
          <body name="camera_stereo_center_optical_frame" pos="0 0 0" quat="0.5 -0.5 0.5 -0.5" />
        </body>
        <inertial mass="0.072" pos="-0.0128694249701 0.00749993845949 -0.000111432996229" fullinertia="4.51419021344e-05 6.75347231905e-06 4.552680228e-05 6.82763116644e-11 2.83927023944e-08 -4.60467569402e-11" />
        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
      </body>
      <body name="imu_link" pos="0 0 -0.0246" quat="0.707106781187 0 0 -0.707106781187">
        <body name="imu_sensor_frame" pos="0 0 0" quat="1 0 0 0">
          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
        </body>
        <inertial mass="0.0024" pos="-0.006458225547 0.0101999383282 0.00111494988099" fullinertia="1.36603078526e-07 5.61002794848e-08 1.88587622299e-07 1.50712337022e-10 5.50310477148e-12 -1.14889063875e-10" />
        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
      </body>
      <inertial mass="0.7918999999999999" pos="0.00644967329592 0.000243242209539 -0.0339474125033" fullinertia="0.00190943161553 0.00321018044161 0.00452838207579 -1.98819430021e-05 9.94823399427e-05 1.49596539567e-05" />
      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
    </body>
  </worldbody>
  <equality>
    <joint name="rocker_differential" joint1="right_rocker_joint" joint2="left_rocker_joint" polycoef="0 -1 0 0 0" solref="0.002 1" />
  </equality>
  <actuator>
    <position name="fl_steering_joint_actuator" joint="fl_steering_joint" kp="10" kv=".3" ctrlrange="-1.57079632679 1.57079632679" forcerange="-2.942 2.942" />
    <velocity name="fl_wheel_joint_actuator" joint="fl_wheel_joint" kv=".2" ctrlrange="-8 8" forcerange="-1 1" />
    <position name="fr_steering_joint_actuator" joint="fr_steering_joint" kp="10" kv=".3" ctrlrange="-1.57079632679 1.57079632679" forcerange="-2.942 2.942" />
    <velocity name="fr_wheel_joint_actuator" joint="fr_wheel_joint" kv=".2" ctrlrange="-8 8" forcerange="-1 1" />
    <position name="rl_steering_joint_actuator" joint="rl_steering_joint" kp="10" kv=".3" ctrlrange="-1.57079632679 1.57079632679" forcerange="-2.942 2.942" />
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

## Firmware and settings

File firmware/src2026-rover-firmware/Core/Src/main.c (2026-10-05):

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
/* Includes ------------------------------------------------------------------*/
#include "main.h"

/* USER CODE BEGIN Includes */
#include <stdio.h>
#include <stdlib.h>
#include <math.h>
#include <string.h>
#include "motor.h"
#include "encoder.h"
#include "sts3215.h"
#include "joint.h"
#include "swerve_kinematics.h"
#include "mdd3a_driver.h"
#include "drive_align_gate.h"
#include "spi_link.h"
#include "pi_spi.h"
#include "imu_ism330.h"
/* USER CODE END Includes */

/* USER CODE BEGIN PTD */
typedef struct {
    int32_t  last_raw_count;  /**< Previous raw encoder tick */
    int64_t  total_count;     /**< Cumulative tick count (no rollover) */
    float    rpm;             /**< Wheel RPM */
    float    rad_per_sec;     /**< Angular velocity [rad/s] */
    float    linear_vel;      /**< Linear velocity [m/s] = w * R */
} WheelState_t;
/* USER CODE END PTD */

/* USER CODE BEGIN PD */
/* Motor & Encoder Specifications */
#define GEAR_RATIO          131.0f             /**< 131:1 Gearbox reduction (SPG30E-GR131) */
/* 조향 가동범위는 바퀴마다 다르다 (구동모터가 몸체 안쪽을 향하게 고정).
 * joint.c 의 joint_config[].min_deg/max_deg 가 유일한 정본이고, Swerve_Control 이
 * 매 주기 읽어서 swerve_fold_to_range 에 넘긴다. */

/* 제어주기.  시뮬(sim/rl/env.py CTRL_HZ=50)과 같은 50Hz.
 * 명령(UART V / SPI)은 목표값만 바꾸고, IK·정렬 게이트·서보·PWM·텔레메트리는
 * 전부 이 주기에서만 나간다. */
#define CTRL_PERIOD_MS          20U

/* 구동 정렬 게이트 (sim/rl/env.py 의 drive_align_gate 와 같은 값).
 * 목표 조향각이 한 주기에 60도 넘게 바뀌면, 네 바퀴 실제각이 목표의 10도 안에
 * 들 때까지 구동을 보류한다.  0 으로 두면 게이트 OFF. */
#define DRIVE_GATE_TRIGGER_DEG  60.0f
#define DRIVE_GATE_RELEASE_DEG  10.0f
/* 이 시간 넘게 정렬이 안 되면 (모래에서 정지 조향이 안 먹힘, 기구 간섭 등) 보류를
 * 풀고 텔레메트리 GATE_TIMEOUT 을 세운다. 영원히 구동이 막히는 교착 방지. */
#define DRIVE_GATE_MAX_HOLD_MS  1500U

#define ENCODER_PPR         16.0f              /**< 16 pulses per motor rev. 2026-10-03 확인: MOT 1 799 2000 무부하 77.8 rpm (정격 76) */
#define ENCODER_CPR         (ENCODER_PPR * 4.0f) /**< 64 ticks in 4x mode (TIM_ENCODERMODE_TI12) */
#define TICKS_PER_REV       (ENCODER_CPR * GEAR_RATIO) /**< 8384.0 ticks per wheel rev */

/* Wheel radius R (Diameter 96mm -> Radius 48mm = 0.048m) */
/* 조립 STL 실측값.  이전 0.048f (지름 96mm) 는 설계 초기 추정치였고 실측과
 * 20.2% 차이가 났다.  개루프 duty 에서는 "보고되는 속도가 틀리다" 로 끝나지만,
 * 바퀴 속도 PI 폐루프를 넣으면 PI 가 틀린 측정값을 목표에 맞추려고 duty 를
 * 계속 왜곡하므로 치명적이다.  sim/rl/config.py 의 wheel_r 과 같은 값이어야 한다. */
#define WHEEL_RADIUS_M      0.03995f           /**< Radius R = 39.95mm (Diameter 79.9mm), STL 실측 */
#define PI                  3.1415926535f

/* --- Swerve module geometry & actuator mapping (bench-test placeholder) ---
 * x=forward, y=left, matches firmware/common/tests/test_swerve_kinematics.c
 * and sim/mujoco/ksrc_rover.urdf. Real offsets pending CAD; module<->MOTOR/
 * servo-ID mapping is also unconfirmed against actual wiring -- both
 * placeholders until bench-verified. Servo IDs use joint.c's array index
 * (0-based; joint_config[] maps index->bus ID internally). */
/* 2026-10-03 실측: 중심 -> 앞/뒤 조향축 105mm, 좌/우 132.5mm (조향축 = 바퀴 중심).
 * sim/rl/config.py 의 axle_x=0.105, track=0.265 (-> track/2=0.1325) 와 같아야 한다.
 * 이전 STL 값 (±0.0918, ±0.11835).
 * 이전 (±0.12, ±0.12) 는 추정치였다.  순수 병진(vx, vy)에서는 모듈 위치가 결과에
 * 영향을 주지 않지만 omega != 0 이면 v_i = v_B + omega x r_i 로 오차가 남는다:
 *     제자리회전 w=0.8  -> 조향각 최대 7.20도
 *     선회 vx=0.2 w=0.5 -> 최대 5.15도
 *     실주행 중앙값     -> 0.90도
 * 시뮬과 반드시 같은 값이어야 한다 (같은 C 코드를 공유하는 의미가 없어진다). */
static const swerve_module_pos_t SWERVE_MODULES[SWERVE_NUM_MODULES] = {
    { 0.105f,  0.1325f },  /* module 0: FL */
    { 0.105f, -0.1325f },  /* module 1: FR */
    {-0.105f,  0.1325f },  /* module 2: RL */
    {-0.105f, -0.1325f },  /* module 3: RR */
};
/* 모듈 -> 구동모터.  2026-10-03 확정: 모터 번호 배치는 조향 서보와 같다.
 *     MOTOR1 LF   MOTOR3 RF
 *     MOTOR2 LB   MOTOR4 RB
 * 모듈 순서는 FL, FR, RL, RR 이므로 {MOTOR1, MOTOR3, MOTOR2, MOTOR4}. */
static const MotorID SWERVE_MODULE_MOTOR[SWERVE_NUM_MODULES] = { MOTOR1, MOTOR3, MOTOR2, MOTOR4 };

/* 모듈 -> 조향 서보 인덱스 (joint_config[] 인덱스 = 서보 ID - 1).
 *     서보1 LF   서보3 RF
 *     서보2 LB   서보4 RB
 * 모듈 순서는 FL, FR, RL, RR 이므로 {서보1, 서보3, 서보2, 서보4}. */
static const uint8_t SWERVE_MODULE_SERVO[SWERVE_NUM_MODULES] = { 0, 2, 1, 3 };

/* ★ 조립 후 확인 (TODO): 구동모터·엔코더 부호. 지금은 전부 +1 (미확인).
 * 좌우 모터가 거울 대칭으로 달리면 한쪽은 -1 이어야 한다. 틀리면 V 0.1 0 0 이
 * 전진이 아니라 제자리 회전이 된다.  확인 방법 (바퀴를 띄운 상태):
 *   1) MTEST 로 모터를 하나씩 돌려 MOTOR1..4 가 어느 바퀴인지 -> SWERVE_MODULE_MOTOR
 *   2) V 0.05 0 0 에서 전진 방향으로 안 도는 바퀴 -> 그 모터의 MOTOR_DRIVE_SIGN = -1
 *   3) 그 상태에서 LOG 의 m/s 가 음수로 나오는 바퀴 -> ENCODER_SIGN = -1
 * 인덱스는 MOTOR1..MOTOR4 (모듈 순서가 아님). 옵시디언 "실기 확인 목록" 에도 기록. */
/* 구동·엔코더 부호.  인덱스는 모터 번호: MOTOR1 LF, MOTOR2 LB, MOTOR3 RF, MOTOR4 RB.
 *
 * 모터는 넷 다 같은 방식으로 단다 (몸체 안에서 바깥을 보고, 샤프트에 바퀴).
 * 그래서 같은 duty + 면 넷 다 샤프트 기준 같은 방향으로 돌고, 샤프트가 좌우로
 * 반대를 보므로 **왼쪽과 오른쪽은 반대로 구른다** -> 부호는 L 끼리 같고 R 끼리 같다.
 *
 * 2026-10-03 로버에 달고 확인: LF·LB 는 duty + 에서 후진 -> L = -1, RB 는 전진 -> R = +1.
 * (RF 는 -1 로 관찰됐지만 대칭에 맞지 않아 +1 로 둔다. V 0.05 0 0 에서 RF 만 뒤로
 *  구르면 RF 모터 출력선(M+/M-)이 반대로 꽂힌 것 -> 부호가 아니라 **선을 바꿔** 고친다.
 *  부호로 덮으면 RF 의 엔코더 부호만 어긋난다.)
 *
 * 엔코더는 전원선과 무관하게 실제 회전을 센다. MOTOR1 이 duty + 에서 tick + 였으므로
 * (bench 실측) 전진할 때 + 가 되려면 ENCODER_SIGN = MOTOR_DRIVE_SIGN.
 * 확인: V 0.05 0 0 에서 넷 다 앞으로 구르고, LOG 의 M1~M4 m/s 가 넷 다 + . */
static const int8_t MOTOR_DRIVE_SIGN[MOTOR_COUNT] = { -1, -1, +1, +1 };
static const int8_t ENCODER_SIGN[MOTOR_COUNT]     = { -1, -1, +1, +1 };

/* Placeholder until bench-measured (free-spin m/s at 100% duty, see
 * mdd3a_driver.h's open item). Wrong magnitude only scales wheel speed
 * for a given vx/vy/omega, doesn't change direction/shape. */
/* 듀티 100% 에서의 바퀴 선속도.  시뮬은 mot_w_noload * wheel_r = 7.96 * 0.03995
 * = 0.318 m/s 로 계산한다.  이 값이 어긋나면 IK 의 desaturation 기준이 달라져
 * 같은 cmd_vel 에 대해 시뮬과 실기의 스로틀 스케일이 맞지 않는다.
 * 실기 벤치테스트로 확정할 값이고, 지금은 시뮬과 일치시킨다. */
#define SWERVE_MAX_WHEEL_MPS  0.318f

/* STS3215 레지스터 중 sts3215.h 에 없는 것 (공식 메모리표 기준) */
#define STS_REG_ID_ADDR    0x05  /**< 서보 버스 ID (EPROM, 0~253) */
#define STS_REG_LOCK_FLAG  0x37  /**< 잠금 플래그: 0 = EPROM 쓴 값이 전원 차단 후에도 유지 (기본값) */
/* USER CODE END PD */

TIM_HandleTypeDef htim1;
TIM_HandleTypeDef htim2;
TIM_HandleTypeDef htim3;
TIM_HandleTypeDef htim4;
TIM_HandleTypeDef htim5;
TIM_HandleTypeDef htim8;
TIM_HandleTypeDef htim12;

/* USER CODE BEGIN PV */

/* === 터미널 명령 수신 버퍼 (USART2 RX 인터럽트) === */
#define CMD_BUF_SIZE  64
static char     cmd_buf[CMD_BUF_SIZE];  /**< ISR 이 문자를 모으는 버퍼 */
static char     cmd_line[CMD_BUF_SIZE]; /**< 완성된 줄 (메인 루프가 읽음) */
static uint8_t  cmd_idx = 0;            /**< 현재 버퍼 인덱스 */
static volatile uint8_t cmd_ready = 0;  /**< 1이면 완성된 명령이 있음 */

/** 주기적 엔코더/속도 로그 출력 여부. 조이스틱이나 SCAN/ZERO 같은 대화형
 *  작업 중에는 10Hz x 5줄이 터미널을 덮어버려서 끌 수 있어야 한다. */
static uint8_t  s_log_enabled = 1;

/** 부팅 모터 자가시험. 예전에는 기본으로 돌아서 전원을 넣으면 첫 주행 명령이 올
 *  때까지 바퀴가 2~3초씩 무한 반복으로 돌았다 (Pi 부팅 전 로버가 스스로 움직임).
 *  이제 기본 OFF 이고 터미널 MTEST 로만 켠다. */
static uint8_t  s_mtest_enabled = 0;

/** 텔레옵 중 5Hz 상태줄 ([CTRL] 받은 vx vy w / 조향각 / duty). 엔코더 로그(LOG)와
 *  따로 켠다 -- 조이스틱이 보낸 값이 STM 에 제대로 들어오는지 확인용.
 *  텔레옵이 시작돼도 꺼지지 않는다. 한 줄 ~90B 라 200ms 마다 ~8ms 송신 대기. */
static uint8_t  s_ctrl_log = 0;

/** 받은 문자를 되돌려 보낼지. 안 그러면 터미널에서 타이핑이 안 보인다.
 *  ISR 에서 송신 대기를 하므로 조이스틱이 연속 전송할 때는 수신 오버런을
 *  유발할 수 있어, 텔레옵이 시작되면 자동으로 꺼진다. */
static uint8_t  s_echo_enabled = 1;

/* === 텔레옵 상태 === */
/** 명령이 이 시간 이상 끊기면 목표 속도를 0 으로 (조이스틱 종료/USB·SPI 분리 대비) */
#define TELEOP_TIMEOUT_MS  500
static uint8_t  s_teleop_active = 0;      /**< 구동 명령을 한 번이라도 받으면 1 */
static uint32_t s_last_cmd_ms = 0;        /**< 마지막 구동 명령 시각 */
static uint8_t  s_teleop_timed_out = 0;   /**< 워치독이 이미 정지시켰으면 1 */
static float    s_cmd_target[3] = {0};    /**< 마지막으로 받은 (vx, vy, omega) */
static uint8_t  s_cmd_from_spi = 0;       /**< 마지막 명령 출처 (1=SPI, 0=UART) */

/* === 제어주기 결과 (텔레메트리로 나간다) === */
static float    s_cmd_applied[3] = {0};              /**< 워치독 적용 후 IK 입력 */
static float    s_steer_goal_rad[SWERVE_NUM_MODULES]; /**< 접은 뒤 목표 조향각 */
static int16_t  s_duty_applied[SWERVE_NUM_MODULES];   /**< 게이트 적용 후 duty */
static uint8_t  s_servo_read_err = 0;
static uint8_t  s_steer_clamped = 0;
static drive_align_gate_t s_gate;

/* === 센서 (매 제어주기 읽음, 모듈 순서 FL, FR, RL, RR) === */
/** 읽기 실패한 서보는 이 주기 수만큼 건너뛴다. 응답 없는 서보 하나가 매 주기
 *  수신 타임아웃(15ms)을 먹어 20ms 주기를 밀어내지 않게 한다. */
#define SERVO_RETRY_TICKS  25U   /* 0.5 s */
static JointFeedback_t s_servo_fb[SWERVE_NUM_MODULES];
static uint8_t  s_servo_valid = 0;                      /**< 비트 m = 모듈 m 이번 주기 유효 */
static uint8_t  s_servo_skip[SWERVE_NUM_MODULES] = {0}; /**< 남은 건너뛰기 주기 */
static uint8_t  s_servo_failed[SWERVE_NUM_MODULES] = {0}; /**< 직전 읽기 실패 */
static int16_t  s_imu_raw[6] = {0};                     /**< gyro xyz, acc xyz */
static uint8_t  s_imu_valid = 0;

/* === Pi SPI 링크 상태 === */
static uint8_t  s_spi_seq_echo = 0;       /**< 마지막으로 받아들인 프레임 seq */
static uint16_t s_spi_rx_err = 0;         /**< 버린 프레임 수 (CRC/동기/길이/비유한값) */

/* USER CODE END PV */

void SystemClock_Config(void);
static void MX_GPIO_Init(void);
static void MX_TIM1_Init(void);
static void MX_TIM2_Init(void);
static void MX_TIM3_Init(void);
static void MX_TIM4_Init(void);
static void MX_TIM5_Init(void);
static void MX_TIM8_Init(void);
static void MX_TIM12_Init(void);
/* USER CODE BEGIN PFP */
static void MX_USART2_Init(void);
static void MX_USART3_Init(void);
static void servo_boot_sequence(void);
static void process_command(const char *cmd);
static void print_help(void);
static void Swerve_Control(float vx, float vy, float omega);
static void teleop_command(float vx, float vy, float omega, uint8_t from_spi);
static void pi_spi_poll(void);
static void read_sensors(void);
/* USER CODE END PFP */

/* USER CODE BEGIN 0 */
static void MX_USART2_Init(void)
{
  __HAL_RCC_GPIOA_CLK_ENABLE();
  __HAL_RCC_USART2_CLK_ENABLE();

  /* PA2: USART2_TX, PA3: USART2_RX (Connected to ST-LINK VCP) */
  GPIO_InitTypeDef GPIO_InitStruct = {0};
  GPIO_InitStruct.Pin = GPIO_PIN_2 | GPIO_PIN_3;
  GPIO_InitStruct.Mode = GPIO_MODE_AF_PP;
  GPIO_InitStruct.Pull = GPIO_PULLUP;
  GPIO_InitStruct.Speed = GPIO_SPEED_FREQ_VERY_HIGH;
  GPIO_InitStruct.Alternate = GPIO_AF7_USART2;
  HAL_GPIO_Init(GPIOA, &GPIO_InitStruct);

  /* Configure Baud rate 115200 (Auto-calculated based on APB1 clock) */
  uint32_t pclk1 = HAL_RCC_GetPCLK1Freq();
  USART2->BRR = (pclk1 + (115200 / 2)) / 115200;
  USART2->CR1 = USART_CR1_TE | USART_CR1_RE | USART_CR1_UE;
}

int __io_putchar(int ch)
{
  while (!(USART2->SR & USART_SR_TXE));
  USART2->DR = (uint8_t)ch;
  return ch;
}

int _write(int file, char *ptr, int len)
{
  (void)file;
  for (int i = 0; i < len; i++)
  {
    if (*ptr == '\n')
    {
      __io_putchar('\r');
    }
    __io_putchar(*ptr++);
  }
  return len;
}

/* Newlib-nano syscall stubs (required when using printf with nano.specs) */
int _read(int file, char *ptr, int len)   { (void)file; (void)ptr; (void)len; return 0; }
int _close(int file)                      { (void)file; return -1; }
int _isatty(int file)                     { (void)file; return 1; }
int _lseek(int file, int ptr, int dir)    { (void)file; (void)ptr; (void)dir; return 0; }
#include <sys/stat.h>
int _fstat(int file, struct stat *st)     { (void)file; st->st_mode = S_IFCHR; return 0; }
int _getpid(void)                         { return 1; }
int _kill(int pid, int sig)               { (void)pid; (void)sig; return -1; }

/* ================================================================== */
/*        USART3 초기화 — STS3215 서보 통신 (PB10/PB11, 1Mbps)        */
/* ================================================================== */
static void MX_USART3_Init(void)
{
  /* GPIO 클럭 및 USART3 클럭 활성화 */
  __HAL_RCC_GPIOB_CLK_ENABLE();
  __HAL_RCC_USART3_CLK_ENABLE();

  /* PB10: USART3_TX (Single-Wire Half-Duplex 모드, 이 핀 하나로 송수신 동시 처리) */
  GPIO_InitTypeDef GPIO_InitStruct = {0};
  GPIO_InitStruct.Pin = GPIO_PIN_10;                 /* PB10 하나만 사용 */
  GPIO_InitStruct.Mode = GPIO_MODE_AF_OD;            /* ★ 반드시 Open-Drain으로 설정 */
  GPIO_InitStruct.Pull = GPIO_PULLUP;                /* 내부 풀업 활성화 */
  GPIO_InitStruct.Speed = GPIO_SPEED_FREQ_VERY_HIGH;
  GPIO_InitStruct.Alternate = GPIO_AF7_USART3;
  HAL_GPIO_Init(GPIOB, &GPIO_InitStruct);

  /* Configure Baud rate 1000000 (1Mbps, Auto-calculated based on APB1 clock) */
  uint32_t pclk1 = HAL_RCC_GetPCLK1Freq();
  USART3->BRR = (pclk1 + (1000000 / 2)) / 1000000;
  
  /* CR3: HDSEL (Half-Duplex Selection) 비트 세트 */
  USART3->CR3 |= USART_CR3_HDSEL;
  
  /* CR1: 송수신 활성화 및 USART 활성화 */
  USART3->CR1 = USART_CR1_TE | USART_CR1_RE | USART_CR1_UE;
}

/* ================================================================== */
/*        USART2 RX 인터럽트 초기화 및 바이트 처리 루틴               */
/* ================================================================== */
static void MX_USART2_RxInt_Init(void)
{
  /* USART2 RXNE 인터럽트 활성화 */
  USART2->CR1 |= USART_CR1_RXNEIE;
  HAL_NVIC_SetPriority(USART2_IRQn, 5, 0);
  HAL_NVIC_EnableIRQ(USART2_IRQn);
}

void USART2_Process_Rx_Byte(uint8_t byte)
{
  char ch = (char)byte;

  /* 엔터(\r 또는 \n) → 명령 완성
   *
   * 이전 구현은 cmd_ready 가 1인 동안 들어오는 문자를 전부 버렸다. 메인
   * 루프가 직전 명령을 처리하는 사이에 도착한 줄이 통째로 사라져서,
   * 조이스틱처럼 20Hz 로 계속 보내면 명령이 끊기고 조각만 남았다.
   * 완성된 줄은 별도 버퍼로 옮기고 수집은 계속한다 — 아직 안 읽힌 줄이
   * 있으면 새 줄이 덮어쓴다(최신 우선). 오래된 속도 명령을 실행하는 쪽이
   * 최신 명령을 놓치는 것보다 위험하므로 이 방향이 맞다. */
  if (ch == '\r' || ch == '\n')
  {
    /* 빈 줄(CRLF 의 두 번째 문자 등)은 무시 — 에코도, 명령 확정도 하지 않는다 */
    if (cmd_idx > 0)
    {
      if (s_echo_enabled) { __io_putchar('\r'); __io_putchar('\n'); }
      cmd_buf[cmd_idx] = '\0';
      memcpy(cmd_line, cmd_buf, (size_t)cmd_idx + 1);
      cmd_ready = 1;
      cmd_idx = 0;
    }
  }
  else if (ch == '\b' || ch == 0x7F)  /* Backspace / DEL — 오타 수정 */
  {
    if (cmd_idx > 0)
    {
      cmd_idx--;
      if (s_echo_enabled) { __io_putchar('\b'); __io_putchar(' '); __io_putchar('\b'); }
    }
  }
  else if (cmd_idx < CMD_BUF_SIZE - 1)
  {
    cmd_buf[cmd_idx++] = ch;
    if (s_echo_enabled) __io_putchar(ch);
  }
}
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
int main(void)
{

  /* MCU Configuration--------------------------------------------------------*/

  /* Reset of all peripherals, Initializes the Flash interface and the Systick. */
  HAL_Init();

  /* Configure the system clock */
  SystemClock_Config();

  /* Initialize all configured peripherals */
  MX_GPIO_Init();
  MX_TIM1_Init();
  MX_TIM2_Init();
  MX_TIM3_Init();
  MX_TIM4_Init();
  MX_TIM5_Init();
  MX_TIM8_Init();
  MX_TIM12_Init();
  /* USER CODE BEGIN 2 */
  MX_USART2_Init();
  Motor_Init();
  Encoder_Init();

  printf("\r\n==================================================\r\n");
  printf("     STM32F446RE Rover Motor & Encoder Test       \r\n");
  printf("==================================================\r\n");
  printf("Baud rate: 115200 bps\r\n");
  printf("Motor Speed: +/-400 (PWM Duty ~50%%)\r\n\r\n");

  /* === 서보 모터 초기화 === */
  MX_USART3_Init();           /* USART3 (PB10/PB11, 1Mbps) 레지스터 초기화 */
  sts_init();                 /* STS3215 드라이버 초기화 */
  MX_USART2_RxInt_Init();     /* USART2 RX 인터럽트 활성화 */
  servo_boot_sequence();      /* PING → 토크 ON → 준비 완료 메시지 */
  drive_gate_init(&s_gate, DRIVE_GATE_TRIGGER_DEG * PI / 180.0f,
                  DRIVE_GATE_RELEASE_DEG * PI / 180.0f,
                  DRIVE_GATE_MAX_HOLD_MS / CTRL_PERIOD_MS);
  PiSpi_Init();               /* SPI2 슬레이브 (Pi 링크, PB12/PB13/PC2/PC3) */
  printf("IMU (ISM330DHCX, SPI3): %s\r\n",
         Imu_Init() ? "OK" : "응답 없음 (배선/CS=PC9 확인, 1초마다 재시도)");

  HAL_Delay(1000);
  /* USER CODE END 2 */

  /* Infinite loop */
  /* USER CODE BEGIN WHILE */
  WheelState_t wheels[MOTOR_COUNT] = {0};
  uint32_t last_log_time = HAL_GetTick();
  /* 엔코더 속도 추정을 **로깅과 분리**한다.  예전엔 last_log_time 하나로 둘을
   * 같이 돌려서, 로그 주기를 바꾸면 속도 추정 주기까지 바뀌었다 (그리고 10Hz 는
   * 바퀴 속도 폐루프에 너무 느리다).
   * 8384 tick/rev 이므로 20ms 창에서도 분해능이 충분하다:
   *     0.20 m/s -> 119 tick / 20ms,   0.02 m/s -> 12 tick / 20ms */
  uint32_t last_enc_time = HAL_GetTick();
  /* 속도 계산용 dt 는 CPU 사이클 카운터로 잰다. HAL_GetTick(1ms) 로 20ms 창을
   * 재면 19/20/21ms 가 섞여 속도에 샘플마다 ±5% 잡음이 생긴다.
   * 16MHz 에서 32비트 카운터는 268초마다 랩하지만 차분만 쓰므로 문제없다. */
  CoreDebug->DEMCR |= CoreDebug_DEMCR_TRCENA_Msk;
  DWT->CYCCNT = 0;
  DWT->CTRL |= DWT_CTRL_CYCCNTENA_Msk;
  uint32_t last_enc_cyc = DWT->CYCCNT;
  const uint32_t ENC_PERIOD_MS = CTRL_PERIOD_MS;  /* 50 Hz 제어주기와 같이 돈다 */
  uint8_t ctrl_tick = 0;
  uint32_t step_start_time = HAL_GetTick();
  uint8_t step = 0;

  /* Initialize last raw counts */
  for (uint8_t i = 0; i < MOTOR_COUNT; i++) {
    wheels[i].last_raw_count = Encoder_GetCount((MotorID)i);
  }

  /* Test parameters */
  const int16_t TEST_SPEED = 400; /* ~50% PWM Duty (PWM_MAX is 799) */

  while (1)
  {
    uint32_t now = HAL_GetTick();

    /* 1a. 엔코더 속도 추정 (50 Hz, 로깅과 독립) */
    if (now - last_enc_time >= ENC_PERIOD_MS)
    {
      uint32_t cyc = DWT->CYCCNT;
      float dt = (float)(cyc - last_enc_cyc) / (float)SystemCoreClock;
      last_enc_cyc = cyc;
      last_enc_time = now;

      for (uint8_t i = 0; i < MOTOR_COUNT; i++)
      {
        int32_t current_raw = Encoder_GetCount((MotorID)i);
        int32_t delta_tick = current_raw - wheels[i].last_raw_count;
        /* TIM1/4/8 are 16-bit: they roll over every 65536 ticks (~7.8 wheel
         * revolutions, ~6 s at full speed).  Without this fold the rollover
         * reads as a 65535-tick jump -> a ~4700 RPM spike on one wheel. */
        if (!Encoder_IsWide((MotorID)i)) delta_tick = (int16_t)delta_tick;
        delta_tick *= ENCODER_SIGN[i];   /* 조립 후 확인할 부호 (위 TODO 참고) */
        wheels[i].last_raw_count = current_raw;
        wheels[i].total_count += delta_tick;

        /* Wheel RPM = (delta_tick / TICKS_PER_REV) * (60.0f / dt) */
        wheels[i].rpm = ((float)delta_tick / TICKS_PER_REV) * (60.0f / dt);

        /* Angular velocity w [rad/s] = RPM * (2*pi / 60) */
        wheels[i].rad_per_sec = wheels[i].rpm * (2.0f * PI / 60.0f);

        /* Linear velocity v [m/s] = w * R */
        wheels[i].linear_vel = wheels[i].rad_per_sec * WHEEL_RADIUS_M;
      }

      /* 1a'. 센서 (항상. 텔레옵 전에도 Pi 가 볼 수 있다) */
      read_sensors();
      if ((ctrl_tick % 50U) == 0U || !s_imu_valid)
      {
        Imu_Check();   /* 1초마다 WHO_AM_I·설정 재확인. 무효가 되면 다음 주기에 바로 재설정 */
      }

      /* 1b. 제어주기 (텔레옵 중에만. 그 전에는 모터 자가시험·T 명령이 액추에이터를 쓴다) */
      if (s_teleop_active)
      {
        /* 워치독: 명령이 끊기면 목표를 0 으로.  모터를 직접 끄는 대신 목표를
         * 0 으로 두어야 다음 주기가 옛 명령을 다시 내보내지 않는다.
         * 조향은 IK 데드밴드가 마지막 각을 유지한다. */
        if (now - s_last_cmd_ms > TELEOP_TIMEOUT_MS)
        {
          if (!s_teleop_timed_out)
          {
            s_teleop_timed_out = 1;
            printf("[텔레옵] 명령 %dms 이상 끊김 — 정지\r\n", TELEOP_TIMEOUT_MS);
          }
          s_cmd_applied[0] = s_cmd_applied[1] = s_cmd_applied[2] = 0.0f;
        }
        else
        {
          s_cmd_applied[0] = s_cmd_target[0];
          s_cmd_applied[1] = s_cmd_target[1];
          s_cmd_applied[2] = s_cmd_target[2];
        }
        Swerve_Control(s_cmd_applied[0], s_cmd_applied[1], s_cmd_applied[2]);
      }

      /* 1c. 텔레메트리 (항상. 텔레옵 전에도 Pi 가 엔코더를 볼 수 있다).
       *     t_ms 는 **Nucleo 시각** -- Pi 수신시각을 쓰면 전송 지터가 오차가 된다. */
      {
        spi_link_telemetry_t t;
        memset(&t, 0, sizeof t);
        t.seq_echo = s_spi_seq_echo;
        t.tick = ctrl_tick++;
        t.flags = (uint16_t)(
            (s_teleop_active    ? SPI_TLM_FLAG_TELEOP_ACTIVE  : 0u) |
            (s_teleop_timed_out ? SPI_TLM_FLAG_WATCHDOG       : 0u) |
            (s_gate.pending     ? SPI_TLM_FLAG_GATE_PENDING   : 0u) |
            (s_cmd_from_spi     ? SPI_TLM_FLAG_SRC_SPI        : 0u) |
            (s_servo_read_err   ? SPI_TLM_FLAG_SERVO_READ_ERR : 0u) |
            (s_steer_clamped    ? SPI_TLM_FLAG_STEER_CLAMPED  : 0u) |
            (s_imu_valid        ? SPI_TLM_FLAG_IMU_VALID      : 0u) |
            (s_gate.timed_out   ? SPI_TLM_FLAG_GATE_TIMEOUT   : 0u));
        t.t_ms = now;
        t.cmd_vx = s_cmd_applied[0];
        t.cmd_vy = s_cmd_applied[1];
        t.cmd_omega = s_cmd_applied[2];
        for (int m = 0; m < SWERVE_NUM_MODULES; m++)
        {
          const WheelState_t *w = &wheels[SWERVE_MODULE_MOTOR[m]];
          t.enc_ticks[m] = (int32_t)w->total_count;
          t.wheel_mps[m] = w->linear_vel;
          t.steer_rad[m] = s_steer_goal_rad[m];
          t.duty[m] = s_duty_applied[m];
          t.steer_meas_rad[m] = s_servo_fb[m].angle_deg * PI / 180.0f;
          t.steer_speed[m] = s_servo_fb[m].speed;
          t.steer_load[m] = s_servo_fb[m].load;
          t.steer_volt[m] = s_servo_fb[m].voltage;
          t.steer_temp[m] = s_servo_fb[m].temp;
          t.steer_status[m] = s_servo_fb[m].status;
        }
        t.servo_valid = s_servo_valid;
        memcpy(t.imu, s_imu_raw, sizeof t.imu);
        t.rx_err = (uint16_t)(s_spi_rx_err + PiSpi_ShortTransfers());
        spi_link_pack_telemetry(&t, PiSpi_TxBuffer());
        PiSpi_CommitTx();
      }
    }

    /* 1d. 로깅 (10 Hz).  printf 는 제어 루프와 절대 같은 주기에 두지 않는다. */
    if (now - last_log_time >= 100)
    {
      float dt = (float)(now - last_log_time) / 1000.0f;
      last_log_time = now;
      if (s_log_enabled)
      {
      printf("[TIME:%6lums | dt:%3dms | R=%dmm]\r\n", now, (int)(dt * 1000.0f),
             (int)(WHEEL_RADIUS_M * 1000.0f + 0.5f));
      for (uint8_t i = 0; i < MOTOR_COUNT; i++)
      {
        int rpm_int = (int)wheels[i].rpm;
        int rpm_frac = (int)(fabsf(wheels[i].rpm) * 10.0f) % 10;
        int rad_int = (int)wheels[i].rad_per_sec;
        int rad_frac = (int)(fabsf(wheels[i].rad_per_sec) * 100.0f) % 100;
        int vel_int = (int)wheels[i].linear_vel;
        int vel_frac = (int)(fabsf(wheels[i].linear_vel) * 1000.0f) % 1000;

        printf(" M%d | Raw:%7ld | %4d.%1d RPM | %3d.%02d rad/s | %2d.%03d m/s\r\n",
               i + 1,
               wheels[i].last_raw_count,
               rpm_int, rpm_frac,
               rad_int, rad_frac,
               vel_int, vel_frac);
      }
      printf("-----------------------------------------------------------------\r\n");
      }  /* if (s_log_enabled) */
    }
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

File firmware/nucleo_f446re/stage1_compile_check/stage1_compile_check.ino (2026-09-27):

/*
 * Stage 1 -- prove firmware/common/*.c (already gcc-host-tested and
 * validated against real vendor protocols) compiles AND runs correctly
 * under STM32duino's ARM toolchain. Still touches zero real I/O
 * (no UART parsing of live bytes, no PWM, no servo bus) -- every call
 * below uses fixed, known inputs with precomputed expected outputs,
 * same values already checked on x86 host in firmware/common/tests/.
 *
 * The PRIMARY pass criterion for Stage 1 is just: this compiles
 * (Sketch > Verify, no board/upload needed). If you do have the board
 * connected and flash this, it also re-checks the results at runtime
 * and reports pass/fail two ways:
 *   - LED_BUILTIN: fast blink (10Hz) = all checks passed,
 *                  slow blink (1Hz)  = something failed
 *   - Serial (115200): prints each check's result if a monitor is open
 *
 * Uses the ksrc_common library (symlinked at
 * ~/Arduino/libraries/ksrc_common/src -> ~/ksrc/firmware/common).
 */
#include <math.h>
#include <string.h>
#include "swerve_kinematics.h"
#include "teleop_protocol.h"
#include "sts3215_protocol.h"
#include "mdd3a_driver.h"

bool g_all_passed = true;

void check(const char *label, bool cond) {
  if (Serial) {
    Serial.print(cond ? "ok   " : "FAIL ");
    Serial.println(label);
  }
  if (!cond) g_all_passed = false;
}

bool near(float a, float b, float tol) {
  return fabsf(a - b) <= tol;
}

void run_checks() {
  // --- swerve_kinematics: pure forward, matches
  // firmware/common/tests/test_swerve_kinematics.c case 1 ---
  {
    swerve_module_pos_t modules[SWERVE_NUM_MODULES] = {
      {0.12f, 0.12f}, {0.12f, -0.12f}, {-0.12f, 0.12f}, {-0.12f, -0.12f}
    };
    swerve_module_state_t state[SWERVE_NUM_MODULES] = {0};
    swerve_module_cmd_t out[SWERVE_NUM_MODULES];
    swerve_ik_compute(1.0f, 0.0f, 0.0f, modules, -1.0f, state, out);
    bool ok = true;
    for (int i = 0; i < SWERVE_NUM_MODULES; i++) {
      ok = ok && near(out[i].angle_rad, 0.0f, 1e-4f) && near(out[i].speed_mps, 1.0f, 1e-4f);
    }
    check("swerve_ik_compute: pure forward", ok);
  }

  // --- teleop_protocol: encode -> parse -> decode round trip against
  // the known cross-checked frame (vx=1.5, vy=-2.25, omega=3.0) ---
  {
    uint8_t buf[TELEOP_VELOCITY_CMD_FRAME_LEN];
    int n = teleop_encode_velocity_cmd(1.5f, -2.25f, 3.0f, buf, sizeof buf);
    teleop_parser_t p;
    teleop_frame_t frame;
    teleop_velocity_cmd_t cmd;
    teleop_parser_init(&p);
    bool decoded = false;
    for (int i = 0; i < n; i++) {
      if (teleop_parser_feed_byte(&p, buf[i], &frame)) decoded = true;
    }
    bool ok = decoded && teleop_decode_velocity_cmd(&frame, &cmd)
              && near(cmd.vx, 1.5f, 1e-5f) && near(cmd.vy, -2.25f, 1e-5f) && near(cmd.omega, 3.0f, 1e-5f);
    check("teleop_protocol: encode/parse/decode round trip", ok);
  }

  // --- sts3215_protocol: known byte vector, id=1 pos=2048 speed=1000 acc=50 ---
  {
    uint8_t buf[32];
    int n = sts3215_build_write_pos_packet(1, 2048, 1000, 50, buf, sizeof buf);
    uint8_t want[] = {0xff,0xff,0x01,0x0a,0x03,0x29,0x32,0x00,0x08,0x00,0x00,0xe8,0x03,0xa3};
    bool ok = (n == (int)sizeof(want)) && (memcmp(buf, want, sizeof want) == 0);
    check("sts3215_protocol: write_pos byte vector", ok);
  }

  // --- mdd3a_driver: forward/reverse mutual exclusion ---
  {
    mdd3a_channel_cmd_t fwd = mdd3a_speed_to_duty(0.6f);
    mdd3a_channel_cmd_t rev = mdd3a_speed_to_duty(-0.6f);
    bool ok = near(fwd.duty_a, 0.6f, 1e-6f) && near(fwd.duty_b, 0.0f, 1e-6f)
              && near(rev.duty_a, 0.0f, 1e-6f) && near(rev.duty_b, 0.6f, 1e-6f);
    check("mdd3a_driver: fwd/rev duty", ok);
  }
}

void setup() {
  pinMode(LED_BUILTIN, OUTPUT);
  Serial.begin(115200);
  uint32_t t0 = millis();
  while (!Serial && millis() - t0 < 2000) {
    // give a monitor up to 2s to attach; proceed either way
  }
  run_checks();
}

void loop() {
  int delay_ms = g_all_passed ? 100 : 500;
  digitalWrite(LED_BUILTIN, HIGH);
  delay(delay_ms);
  digitalWrite(LED_BUILTIN, LOW);
  delay(delay_ms);
}

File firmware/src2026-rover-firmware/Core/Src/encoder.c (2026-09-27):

/**
 * @file    encoder.c
 * @brief   Quadrature encoder implementation (x4 mode, hall-sensor encoders)
 */

/* Includes ------------------------------------------------------------------*/
#include "encoder.h"
#include "main.h"   /* HAL types, Error_Handler, etc. */

/* Private types -------------------------------------------------------------*/

/** Per-encoder hardware descriptor */
typedef struct
{
    TIM_HandleTypeDef *htim;    /**< Encoder timer handle        */
    uint8_t            is32bit; /**< 1 if timer is 32-bit (TIM5) */
} EncoderHW_t;

/* External timer handles (defined in main.c by CubeMX) ---------------------*/
extern TIM_HandleTypeDef htim1;
extern TIM_HandleTypeDef htim4;
extern TIM_HandleTypeDef htim5;
extern TIM_HandleTypeDef htim8;

/* Private variables ---------------------------------------------------------*/

/** Lookup table: MotorID → encoder timer */
static const EncoderHW_t encoderHW[MOTOR_COUNT] =
{
    [MOTOR1] = { .htim = &htim1, .is32bit = 0 },   /* 16-bit, Period = 65535      */
    [MOTOR2] = { .htim = &htim4, .is32bit = 0 },   /* 16-bit, Period = 65535      */
    [MOTOR3] = { .htim = &htim5, .is32bit = 1 },   /* 32-bit, Period = 0xFFFFFFFF */
    [MOTOR4] = { .htim = &htim8, .is32bit = 0 },   /* 16-bit, Period = 65535      */
};

/* Exported functions --------------------------------------------------------*/

void Encoder_Init(void)
{
    for (uint8_t i = 0; i < MOTOR_COUNT; i++)
    {
        HAL_TIM_Encoder_Start((TIM_HandleTypeDef *)encoderHW[i].htim,
                              TIM_CHANNEL_ALL);
    }
}

int32_t Encoder_GetCount(MotorID id)
{
    if (id >= MOTOR_COUNT) return 0;

    const EncoderHW_t *hw = &encoderHW[id];
    uint32_t cnt = __HAL_TIM_GET_COUNTER(hw->htim);

    if (hw->is32bit)
    {
        /* TIM5: 32-bit counter – reinterpret as signed directly */
        return (int32_t)cnt;
    }
    else
    {
        /* 16-bit counter – cast to int16_t first for correct sign extension
         * e.g. 0xFFFF → -1, 0xFFFE → -2, etc. */
        return (int32_t)(int16_t)(uint16_t)cnt;
    }
}

uint8_t Encoder_IsWide(MotorID id)
{
    if (id >= MOTOR_COUNT) return 0U;
    return encoderHW[id].is32bit;
}

void Encoder_Reset(MotorID id)
{
    if (id >= MOTOR_COUNT) return;

    __HAL_TIM_SET_COUNTER(encoderHW[id].htim, 0U);
}

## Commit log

2026-09-27 KSRC 소스 코드 초기 업로드
    [ksrc_rover.urdf]
2026-09-28 Document current RL reward and training environment
2026-10-05 밑단 제어기: Pi SPI 링크 + IMU + 정렬 게이트 + 조향 범위, 실측 기하 반영
    - 펌웨어: SPI2 슬레이브(Pi, 144B v2 프레임), ISM330DHCX(SPI3), 구동 정렬 게이트,
    바퀴별 조향 범위 ±100°, 구동/엔코더 매핑·부호, 실측 바퀴 위치, CTRL 로그
    - pi: nucleo_link SPI 프레임, spi_monitor, 조이스틱 데드존/축 스냅/저속 방향 고정
    - sim/ros: 조향 범위·실측 기하 반영, CAD rover_description
    - 문서: firmware/README·CLI, sim/README·CLI 분리
    [base_link.stl, base_link_sim.stl, camera_link.stl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]
2026-10-05 Pi SPI 링크 실기 안정화 + IMU 자동 복구 + 확인 도구
    - pi_spi: CS 스파이크 필터(PB12 가 실제 High 일 때만 프레임 끝), 소프트웨어 NSS,
    진단 카운터 + SPI 명령, 서보 읽기 중 CS 인터럽트 보류(PiSpi_HoldIrq, USART3 오버런 방지),
    MISO 슬루 LOW
    - imu_ism330: 1초 점검에 설정 레지스터 재확인, 12바이트 동일 프레임 무효 처리 후 즉시 재설정,
    SPI3 슬루 LOW
    - pi: imu_check.py (바이어스 보정, 기울기, 자이로 적분), spi_monitor 에 엔코더 누적 틱 표시
    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
2026-10-05 IMU 칩 좌표 -> 로버 좌표 변환 (z 기준 180도 장착 실측)
    nucleo_link: IMU_CHIP_TO_BODY = x, y 반대 / z 그대로. gyro_dps, acc_g 는 로버 좌표,
    imu_raw 는 칩 원시값 유지.
2026-10-05 라파에서 조이스틱 텔레옵 (SPI 전송) + 문서
    - teleop_joystick: --spi (Pi SPI0 -> Nucleo SPI2), --monitor 는 텔레메트리로
    STM 적용 명령·조향·duty 출력, 창 하단에 STM 수신값 표시
    - firmware CLI/README: SPI 배선 주의(SCLK 분리, GND 직결), [BAD] 원인 좁히기,
    imu_check, ssh -X 로 라파 조이스틱 실행
2026-10-05 조이스틱: PC 창 -> UDP -> 라파 udp_spi_bridge -> SPI
    ssh X 포워딩에서 pygame(SDL 2.30) 창이 MIT-SHM BadRequest 로 죽어(-X, -Y 모두)
    창은 PC 에서 띄우고 라파는 중계만 한다. 라파 브리지: 최신 패킷만 사용, 0.3초 끊기면 0,
    값 클램프, 5Hz 로 텔레메트리 요약 회신. teleop_joystick --udp HOST.
2026-10-14 10-05 이후 작업 일괄: 바퀴 PI·RL 잔차 경로(구조 B)·Isaac 이식·실물 점검 도구
    펌웨어
    - 바퀴 속도 PI (common/wheel_pi.c, WPI/WCAP 명령, 기본 OFF) + 보호 3개:
    보정량 상한 ±250 duty, 스톨(0.5 s, FF 만), 엔코더 방향 불일치(1 s 재시도, 10 s 안 3회면 잠금, ENC_DIR)
    - SPI 타입 0x02: (vx, vy, w) + 바퀴별 조향 잔차·속도 배율. IK·접기 뒤에 더하고 100 ms 타임아웃,
    텔레옵(V, 0x01)은 그대로. 텔레메트리 비트 9·10·11, imu_n
    - IMU 1 ms 폴링 + 20 ms 평균, ICAP 원시 기록
    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
2026-10-14 bringup link: 속도 0 명령으로 텔레옵에 넘겨 로그를 끄고 측정 (폴링만 하면 10 Hz UART 로그로 40 ms 주기가 섞임)
2026-10-14 pi/README.md: 라파 코드 정리 문서 + bringup latency 시계 표류 보정
    latency 를 ms 로: Nucleo t_ms(HSI, Pi 보다 0.3 % 빠름) 와 Pi 시계 차이를 직선으로 맞추고
    가장 신선한 프레임을 나이 0 으로. 10-14 실측: 명령 -> 적용 17.6–46.5 ms, 관측 나이 평균 14 ms.
    Claude-Session: https://claude.ai/code/session_01KBGFM8kxVmde48SmBc9QYb
2026-10-14 bringup log: STALL·ENC_DIR·GATE 가 걸리고 풀리는 순간을 바로 찍음
    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
2026-10-14 펌웨어: 바퀴 PI 기본 ON (10-14 실물 확인)
    벤치 계단 0->2 rad/s 90% 41–51 ms, 지면 0.15 m/s 직진에서 네 바퀴 0.150 m/s
    (개루프 0.120–0.127), 바퀴 간 duty 차이 7 %, 스톨 보호 동작 확인. 개루프는 `WPI OFF`.
    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
2026-10-14 SPI 설정 메시지 0x03: 라파에서 바퀴 PI 켜기/끄기·보정량 상한 + 모래 A/B 루틴
    - 펌웨어: 타입 0x03 (wpi_mode, wpi_corr). 주행 명령 아님(워치독·텔레옵 무관), 바꾸면 PI 상태·잠금 초기화.
    텔레메트리 [140] wpi_corr. 재부팅하면 기본값(ON, 250).
    - nucleo_link: encode_spi_config, SpiLink.config, wpi_corr 해석. C 와 교차검증.
    - bringup.py: `wpi` (켜기/끄기·corr), `sand` (조건 자동 전환, 출발선 Enter, 줄자 입력, 요약 CSV).
    설정 뒤 확인 폴링이 밀린 일정 때문에 옛 프레임을 읽던 문제 수정.
    Claude-Session: https://claude.ai/c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
2026-10-14 실측 반영 학습 설정 + run_policy 루프 주기 통계
    - 시뮬: 지면 하중(복도 실측 +53 duty, 넓힌 DR ×0.6–2.0), 지연 action (1,2) / obs (0,1),
    명령 변화율 제한(속도 크기·방향 분리, 0.5 m/s², 방향 1.5 rad/s, 20 % 즉시). ground_load.py, drive_check 게이트 원인.
    - run_policy: 루프 주기·계산 시간 통계(평균/p95/p99/최대, 25·40 ms 초과 횟수), --rt (SCHED_FIFO), --cpu, --gc-off.
    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
2026-10-14 student 자이로 = 20 ms 평균 IMU (선택 A) + run_policy 첫 추론 예열
    - 시뮬 student 관측 gyro: 참 각속도 순간값 -> 제어주기 평균 (펌웨어 Imu_TakeMean 과 같음, gyro_imu 소스).
    teacher 입력은 그대로. student_obs_check 에 자이로 오차 추가.
    - run_policy: 루프 전에 정책을 3 번 돌려 첫 주기 지연(30 ms 넘음) 제거.
    - 10-14 스모크: 증류 -> export_student -> run_policy --fake 까지 끝까지 돎 (obs 145).
    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
2026-10-14 관측 applied_targets = 정책이 방금 보낸 명령 (지연 전)
    명령 지연을 실측 1–2 스텝으로 바꾸자, 지연 뒤 목표를 관측으로 주던 시뮬에서는 정책이 아직 적용 안 된
    자기 명령을 볼 수 없어 학습이 막혔다 (10-14: 700 iter 에 IK 보다 xy +9 %, 헛돎 감소 없음).
    라파 student_runtime 도 같은 뜻으로 (게이트 중 바퀴 0 처리 제거).
    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
2026-10-16 rev5 원기둥 모델 + 정책 v1 배포 경로 + Isaac 떨림 대책·VO 관측 + 실측 절차
    - rover_description: rev5 URDF 수정본(fix_rev5.py, 원본 오류 7개), Isaac 원기둥 바퀴판, MuJoCo mjcf, 메쉬
    - pi: run_policy (IK 시작 동기화, 정지 시 잔차 0, 원시 텔레메트리 로그), student_runtime VO 항,
    imu_noise, 정책 res8_mlp_v1_rc4000, 실측 절차 MEASURE_1016/1017
    - firmware: SPI 링크 0x03, main.c
    - Isaac: Res8 잔차 변화율 제한·정지 마스크, res_rate 보상, VO 관측(잠정), CMD_MODE nav, DriveGate 실측 트리거
    - ros: isaac_bridge (MuJoCo, /set_rl·/reset_sim, 조향 흔들림 지표), nav2_isaac 런치 (RPP+RotationShim+smoother)
    -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
2026-10-16 MuJoCo 에서 student v3 (VO) 실행 + 문서를 10-16 현황으로 갱신
    - sim2sim_isaac: VoSim (Isaac mdp/vo.py 의 numpy 판), --vo dr|off. isaac_bridge·nav2_isaac 런치에 vo 인자
    - isaac_bridge: 2초 로그에 조향 흔들림 (명령 ±° / 실제 ±°)
    - README·CLI (루트, firmware, pi, sim, Isaac, rover_description): rev5 사양, SPI 0x01~0x03, 바퀴 PI,
    실측으로 확정된 값 (구동·엔코더 부호, 최고속, 서보), nav2_isaac 사용법, Isaac teacher-student 명령·평가 프로토콜,
    현재 결과. 옛 SB3 경로는 옛 구성으로 표시
    Claude-Session: https://claude.ai/code/session_01KBGFM8kxVmde4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

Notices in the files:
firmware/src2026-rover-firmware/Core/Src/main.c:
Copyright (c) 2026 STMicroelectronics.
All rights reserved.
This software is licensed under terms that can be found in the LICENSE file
